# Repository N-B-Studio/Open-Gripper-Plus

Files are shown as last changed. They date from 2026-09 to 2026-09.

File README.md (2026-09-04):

# Open-Gripper-Plus

An open robotic gripper built around a cycloidal gear actuator, dual ODrive motor control, and an STM32H723 control board.

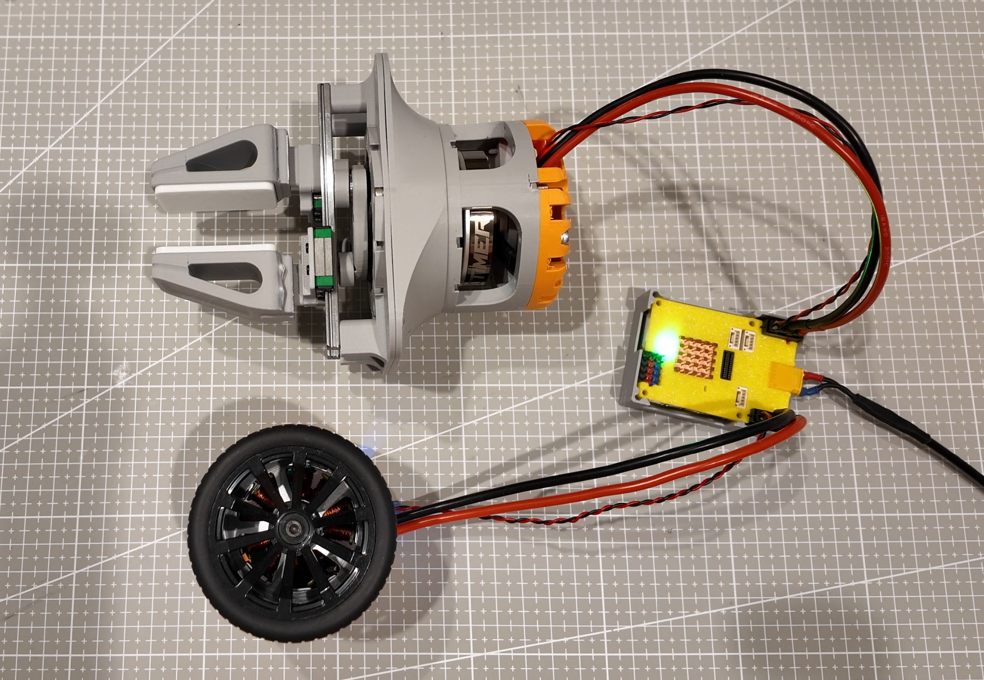
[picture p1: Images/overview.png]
Open-Gripper-Plus assembled prototype


## Overview

Open-Gripper-Plus combines a compact mechanical gripper with embedded control electronics for synchronized actuator operation. The repository includes the mechanical CAD files and the STM32 firmware project used to communicate with the motor controllers.

## Features

- Cycloidal gear actuator and custom gripper parts
- STM32H723VGT6 control board
- Dual FDCAN interfaces for ODrive communication
- BMI088 accelerometer and gyroscope support over SPI
- 1 kHz control loop with position synchronization and torque limits
- UART logging and WS2812 status LEDs

## Repository Layout

```text
3D Model/
	5010+Cycloidal+Gear+Actuator/  Reference actuator CAD
	modified part/                 Custom gripper and actuator parts
Images/                          Project images
STM32-H723/                      STM32CubeIDE firmware project
```

## Firmware

The firmware project is located in [`STM32-H723/`](STM32-H723/). The CubeMX configuration is [`vla-arm.ioc`](STM32-H723/vla-arm.ioc), and the application entry point is [`main.c`](STM32-H723/Core/Src/main.c).

The controller assigns two motor nodes to the leader and follower axes and exchanges motor state over FDCAN. Control parameters such as spring gain, damping, follow ratio, deadband, and torque limits are defined near the top of `main.c`.

### Build

Open [`STM32-H723/vla-arm.ioc`](STM32-H723/vla-arm.ioc) or the project in STM32CubeIDE, select the `Debug` or `Release` configuration, and build for the STM32H723VGT6 target. The generated build output is placed in the corresponding `STM32-H723/Debug/` or `STM32-H723/Release/` directory.

Before powering the actuator, verify the motor node IDs, CAN wiring, motor enable wiring, torque limits, and mechanical travel for your hardware.

## Mechanical Files

The `3D Model/modified part/` directory contains the custom STEP parts:

- `motor-base.step`
- `part-1.step` through `part-6.step`

The `3D Model/5010+Cycloidal+Gear+Actuator/` directory contains the reference actuator model.

## License

This project is released under the [MIT License](LICENSE).

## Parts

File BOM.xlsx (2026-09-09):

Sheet: gribber
Name | Quantitiy | Spec | Taobao
BLDC Motor | 2 | 5010 260kv
M3 bolt | few | 8mm 10mm 12mm 14mm
Bearings | 4
Steel rods | 4 | m3*10 | https://item.taobao.com/item.htm?id=959105247455
Linear rails | 2 | MGN7 100mm | https://item.taobao.com/item.htm?id=762564601721
Linear rail blocks / carriages | 2 | MGN7C | https://item.taobao.com/item.htm?id=762564601721
Bearings | 4 | 3*10*4 | https://detail.tmall.com/item.htm?id=704126548333
Optional components:
Wheels / tyres | 1 | 601-6085 | https://item.taobao.com/item.htm?id=45362002229
Control board |  | DA-kit STM32-H723 | https://item.taobao.com/item.htm?id=775424549365
FOC motor drivers | 2 | MINI_Odrive foc Turing | https://item.taobao.com/item.htm?id=842070935339
Wires
M2 nylon screws | 4 | mount mini-odrive (m2*10) | https://detail.tmall.com/item.htm?id=601483585366
M2 heat-set threaded inserts | 4 | M2*3*3.5 | https://detail.tmall.com/item.htm?id=809364062256

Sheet: gearbox
Category | Item | Description | Quantity | Cost USD | Total Cost USD | US Link | Cost RMB | Total Cost RMB | China Link
 | Bearing | MR106-2RS | Bearing between input shaft and cycloidal disk, and between input shaft and output shaft | 13 | $0.87 | $11.31 | https://www.amazon.com/dp/B082PSCNKB?ref_=cm_sw_r_cp_ud_dp_XR6N8JQ34JH0ZSWHT5HK (https://www.amazon.com/dp/B082PSCNKB?skipTwisterOG=1&newOGT=1) | ¥0.90 | ¥11.70 | https://detail.tmall.com/item.htm?abbucket=9&id=728753970557&skuId=5050168324949
 |  | 6701-2RS | Bearing between cycloidal disk and output shaft | 2 | $0.94 | $1.88 | https://www.amazon.com/gp/product/B082PQ8DC2 | ¥2.30 | ¥4.60 | https://detail.tmall.com/item.htm?abbucket=9&id=672836796497&skuId=5017505094887
 |  | 6809ZZ | Bearing between output shaft and housing | 2 | $2.26 | $4.52 | https://www.amazon.com/gp/product/B082PQQP7W | ¥3.89 | ¥7.78 | https://detail.tmall.com/item.htm?abbucket=8&id=695287603935&ns=1&skuId=5102438922481
 | Fastener | M3 x 55 mm | Mounting housing | 4 | $0.26 | $1.04 | https://www.amazon.com/gp/product/B01N68JLPE/ | ¥0.35 | ¥1.40 | https://detail.tmall.com/item.htm?abbucket=8&id=654819932601&skuId=5014407101270
 |  | M3 x 25 mm | Mounting output shaft | 6 | $0.19 | $1.14 | https://www.amazon.com/gp/product/B0967ZWJMM | ¥0.07 | ¥0.42 | https://detail.tmall.com/item.htm?abbucket=8&id=654819932601&skuId=5014407101291
 |  | M2 x 3 x 3.5 mm | M2 threaded insert for mounting encoder | 4 | $0.07 | $0.28 | https://www.amazon.com/dp/B0B8GN63S2 | ¥0.08 | ¥0.32 | https://detail.tmall.com/item.htm?abbucket=15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
 |  | M3 x 4 x 5 mm insert | M3 threaded insert | 24 | $0.08 | $1.92 | https://www.amazon.com/gp/product/B0BTYF2MMD | ¥0.13 | ¥3.12 | https://item.taobao.com/item.htm?id=593581996419&skuId=4189077672129
 |  | M4 x 12 mm hex stand | input shaft stiffener | 1 | $0.40 | $0.40 | https://www.amazon.com/uxcell-Female-Threaded-Standoff-Pillar/dp/B018RSONJK?s=industrial | ¥0.26 | ¥0.26 | https://detail.tmall.com/item.htm?abbucket=8&id=645528391157
 | Motor | MAD Components 5010 110KV |  | 1 | $84.00 | $84.00 | https://www.amazon.com/gp/product/B082W5B5LZ | ¥448.00 | ¥448.00 | https://item.taobao.com/item.htm?abbucket=8&id=534590842464
 | Structural | PLA | 3D print filament, in kg | 0.1 | $25.99 | $2.60 | https://www.amazon.com/gp/product/B00J0GMMP6 | ¥79.00 | ¥7.90 | https://detail.tmall.com/item.htm?abbucket=8&id=693972799714
 | Electrical | B-G431B-ESC1 | Motor controller | 1 | $18.97 | $18.97 | https://www.digikey.com/en/products/detail/stmicroelectronics/B-G431B-ESC1/10321670 | ¥165.00 | ¥165.00 | https://item.taobao.com/item.htm?abbucket=8&id=656153143517
 |  | AS5600 | I2C position encoder | 1 | $3.30 | $3.30 | https://www.amazon.com/gp/product/B09LMB3PTZ | ¥5.40 | ¥5.40 | https://item.taobao.com/item.htm?abbucket=8&id=828546819482
 |  | Misc | Cables & connectors | 1 | $5.00 | $5.00 |  | ¥20.00 | ¥20.00
 | Total |  |  |  |  | $136.36 |  |  | ¥675.90
reference： | https://berkeley-humanoid-lite.gitbook.io/docs/getting-started-with-hardware/materials-and-parts-bom
print-file： | https://makerworld.com/en/models/1279205-5010-cycloidal-gear-actuator?from=search#profileId-1364911

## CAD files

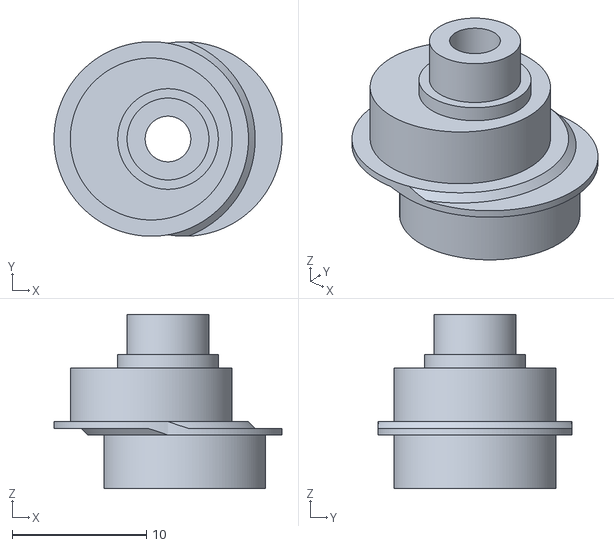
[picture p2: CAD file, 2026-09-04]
3D Model/5010+Cycloidal+Gear+Actuator/Input Shaft - Bambu - Input Shaft.stl
17.0 x 14.5 x 13.0

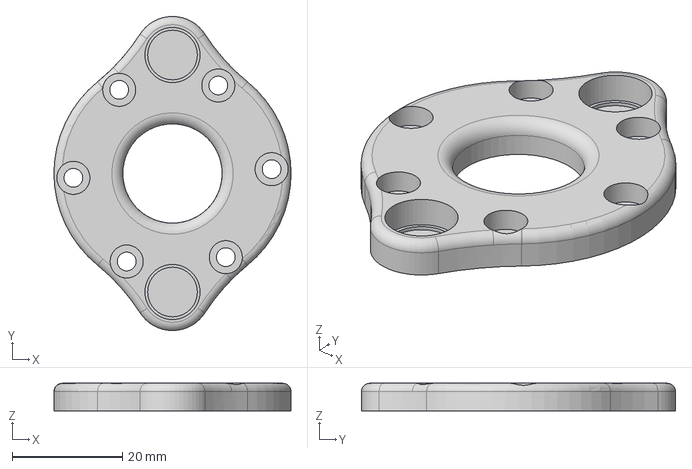
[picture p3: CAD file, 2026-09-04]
3D Model/modified part/part-4.step
43.0 x 57.0 x 5.00 mm

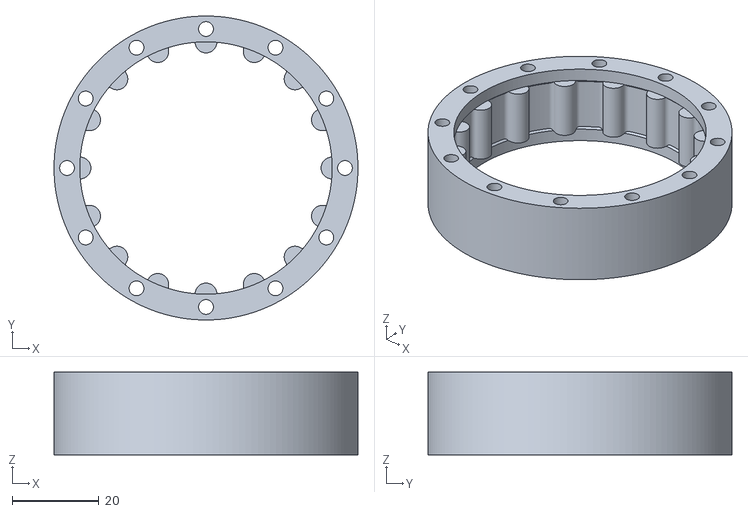
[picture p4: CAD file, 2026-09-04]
3D Model/5010+Cycloidal+Gear+Actuator/Housing - Bambu - Housing Middle.stl
70.0 x 70.0 x 19.0

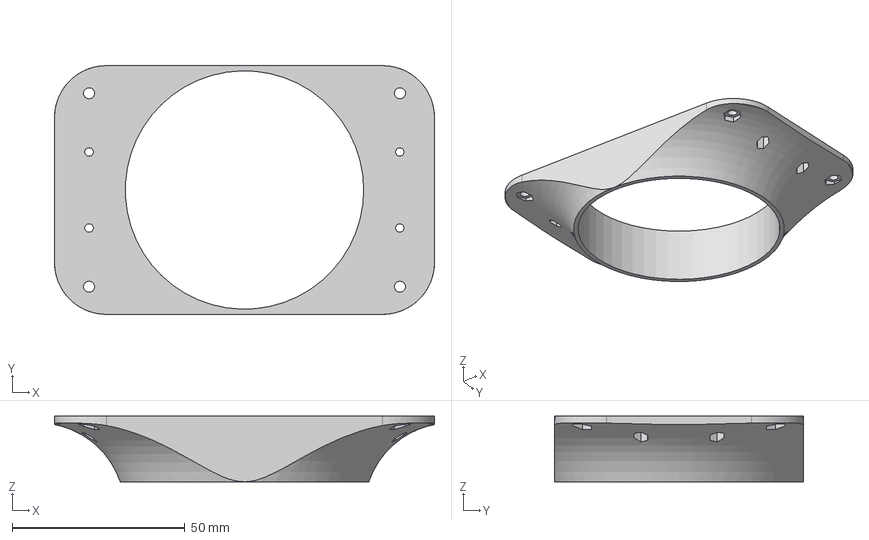
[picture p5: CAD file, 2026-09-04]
3D Model/modified part/part-2.step
110.0 x 72.0 x 19.0 mm

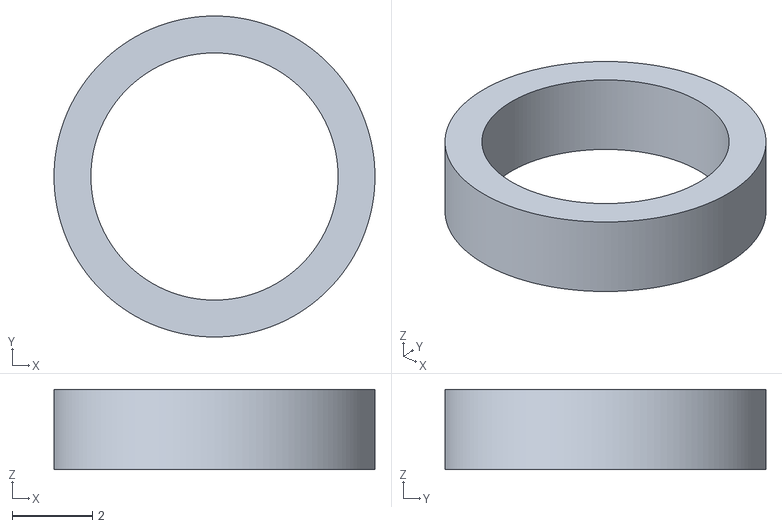
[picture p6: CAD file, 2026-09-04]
3D Model/5010+Cycloidal+Gear+Actuator/Output - Bambu - Output Shaft Spacer.stl
8.00 x 8.00 x 2.00

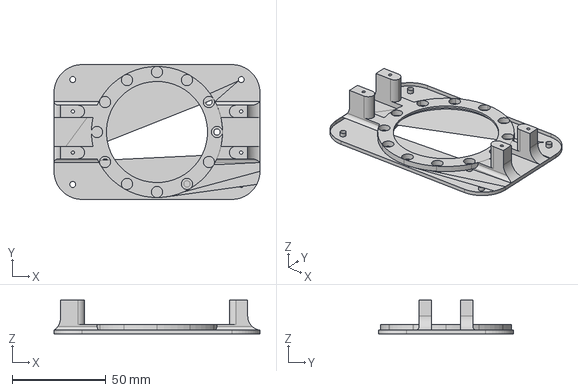
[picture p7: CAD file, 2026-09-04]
3D Model/modified part/part-3.step
110.0 x 72.0 x 18.0 mm

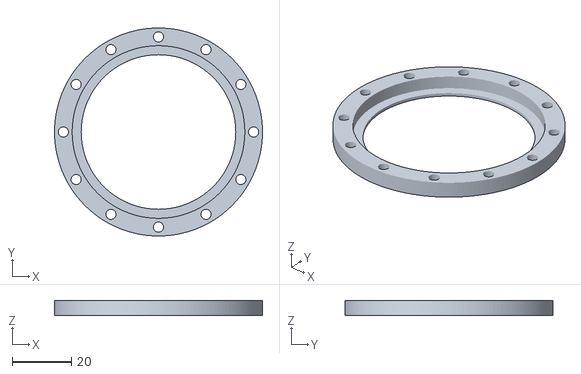
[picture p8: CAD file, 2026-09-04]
3D Model/5010+Cycloidal+Gear+Actuator/Housing - Bambu - Housing Rear.stl
70.0 x 70.0 x 5.00

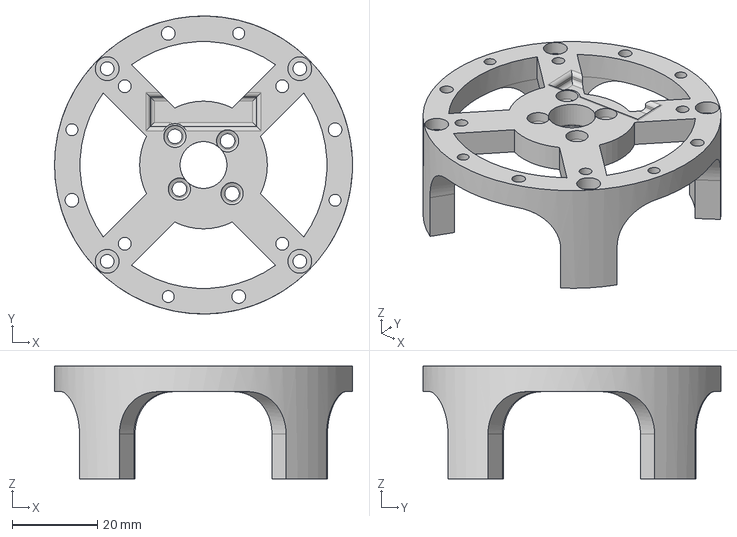
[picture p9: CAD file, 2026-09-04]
3D Model/modified part/motor-base.step
70.0 x 70.0 x 26.5 mm

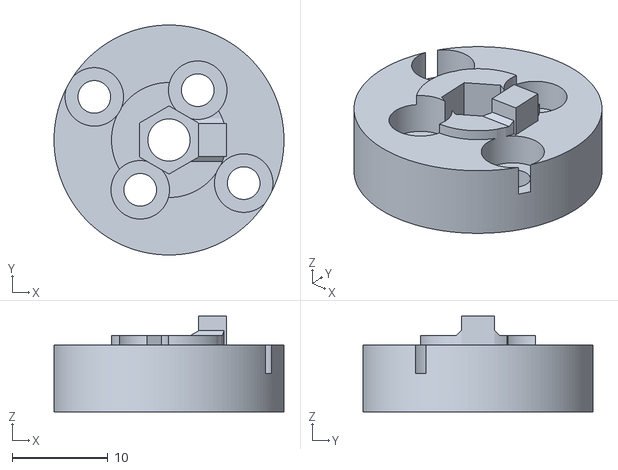
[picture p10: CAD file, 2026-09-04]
3D Model/5010+Cycloidal+Gear+Actuator/Motor Shaft - Bambu - Motor Shaft.stl
24.0 x 24.0 x 10.0

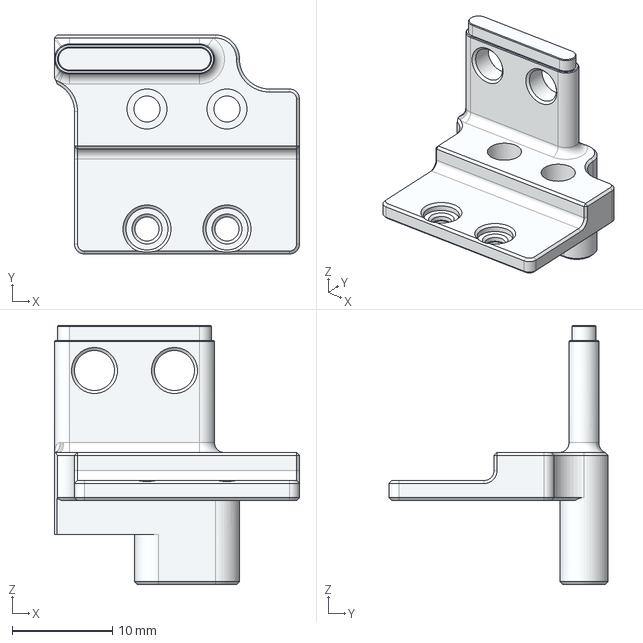
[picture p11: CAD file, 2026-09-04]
3D Model/modified part/part-6.step
24.5 x 21.9 x 25.9 mm

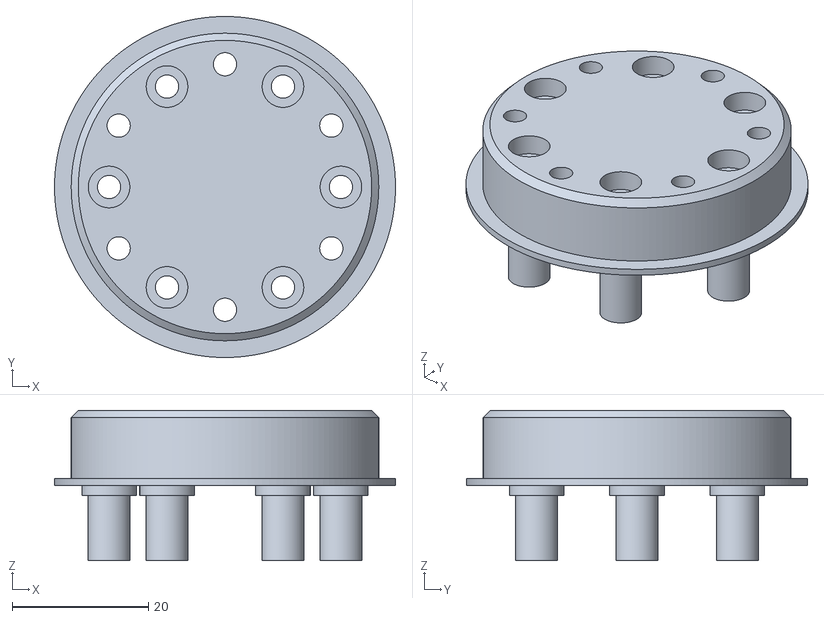
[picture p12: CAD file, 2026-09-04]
3D Model/5010+Cycloidal+Gear+Actuator/Output - Bambu - Output Shaft Front.stl
50.0 x 50.0 x 22.0

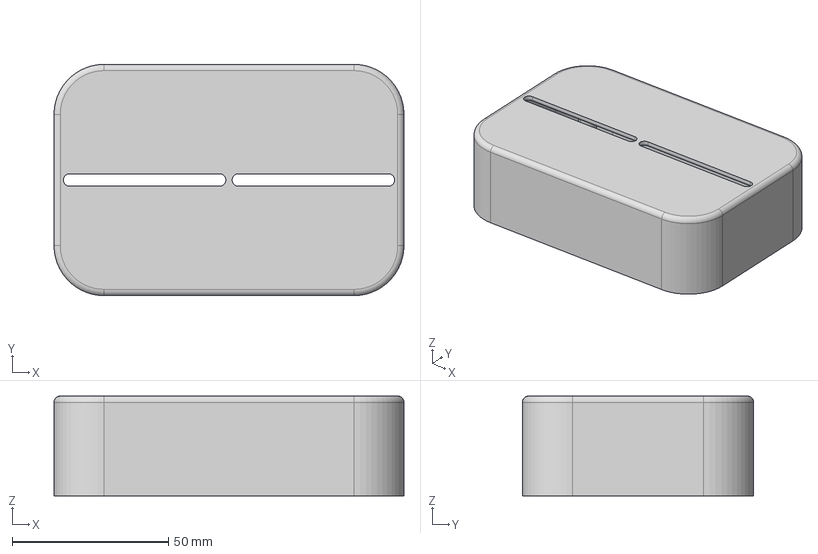
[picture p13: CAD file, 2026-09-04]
3D Model/modified part/part-5.step
112.0 x 74.0 x 32.0 mm

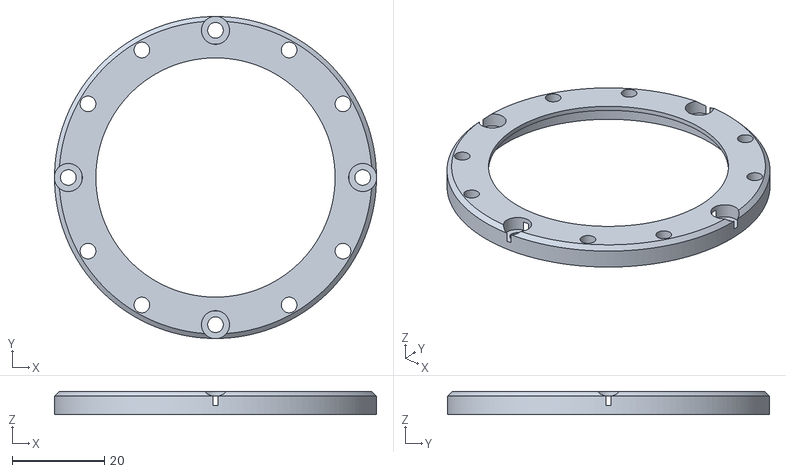
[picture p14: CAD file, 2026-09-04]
3D Model/5010+Cycloidal+Gear+Actuator/Housing - Bambu - Housing Front.stl
70.0 x 70.0 x 5.00

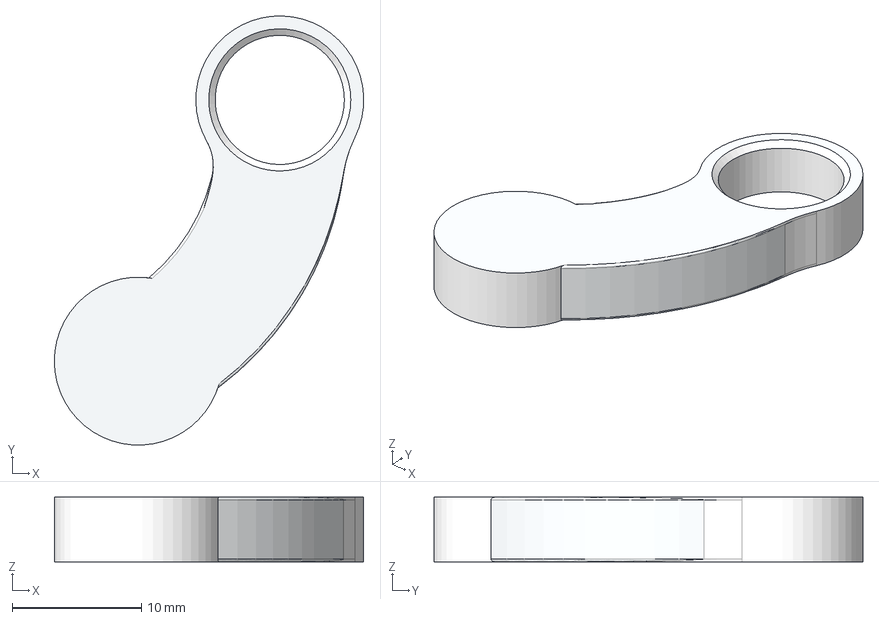
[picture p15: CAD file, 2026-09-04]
3D Model/modified part/part-1.step
23.9 x 33.2 x 5.00 mm

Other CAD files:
3D Model/5010+Cycloidal+Gear+Actuator/Output - Bambu - Output Shaft Rear.stl
3D Model/5010+Cycloidal+Gear+Actuator/Cycloidal Disk - Bambu - Cycloidal Disk.stl
3D Model/5010+Cycloidal+Gear+Actuator/Motor Shell - Motor Shell.stl

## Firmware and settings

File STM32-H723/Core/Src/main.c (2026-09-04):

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
/* Includes ------------------------------------------------------------------*/
#include "main.h"
#include "dma.h"
#include "fdcan.h"
#include "spi.h"
#include "tim.h"
#include "usart.h"
#include "gpio.h"

/* USER CODE BEGIN PD */
#include "ws2812.h"
#include "bsp_fdcan.h"
#include <stdio.h>
#include <string.h>
#include <stdarg.h>
#include <math.h>
/* USER CODE END PD */

/* USER CODE BEGIN PM */
typedef struct {
    uint8_t node_id;
    float pos_turns;
    float vel_turns_s;
    float torque_target_nm;
    float torque_estimate_nm;
    uint32_t axis_error;
    uint8_t axis_state;
    uint32_t hb_count;
    uint32_t enc_count;
    uint32_t tq_count;
    uint32_t last_rx_ms;
} ODriveState;

#define NODE_LEADER    1   // motor on CAN1
#define NODE_FOLLOWER  2   // motor on CAN2

static ODriveState leader   = {NODE_LEADER,   0};
static ODriveState follower = {NODE_FOLLOWER, 0};

extern volatile uint32_t can1_raw_rx_count;
extern volatile uint32_t can2_raw_rx_count;

extern volatile uint16_t can1_last_rx_id;
extern volatile uint16_t can2_last_rx_id;
/* USER CODE END PM */


/* USER CODE BEGIN PV */
volatile uint8_t loop_1khz_flag = 0;
static uint32_t loop_count = 0;
static uint32_t can_tx_drop = 0;
static uint32_t can_rx_other = 0;

#define CTRL_DIV 1   // 1=1kHz, 2=500Hz, 4=250Hz, 10=100Hz

/* Bidirectional virtual spring parameters */
static float K_SPRING = 0.02f;

/* Absolute velocity damping for leader/follower */
static float D_ABS_L = 0.005f;
static float D_ABS_F = 0.0002f;

/* Keep 1:1 initially. After stability confirmed, can change to 7.0f */
static float FOLLOW_RATIO = 15.0f;

/* Velocity low-pass filter coefficient */
static float VEL_LPF_ALPHA = 0.15f;

/* Continuous position deadband, about 0.2 degrees */
static float ERR_DEADBAND_RAD = 0.0035f;

/* Maximum sync error to prevent torque saturation during fast motion */
static float ERR_MAX_RAD = 1.20f;

/* Maximum torque for each side */
static float TAU_MAX_L = 0.80f;
static float TAU_MAX_F = 0.60f;


/* USER CODE END PV */

void SystemClock_Config(void);
/* USER CODE BEGIN 0 */
static inline void led_yellow(void){ WS2812_Ctrl(60, 60, 0); }
static inline void led_red(void)   { WS2812_Ctrl(80, 0, 0);  }
static inline void led_green(void) { WS2812_Ctrl(0, 80, 0);  }

static char logbuf[224];

static void log_uart1(const char *s)
{
    HAL_UART_Transmit(&huart1, (uint8_t*)s, (uint16_t)strlen(s), 100);
}

static void logf_uart1(const char *fmt, ...)
{
    va_list ap;
    va_start(ap, fmt);
    int n = vsnprintf(logbuf, sizeof(logbuf), fmt, ap);
    va_end(ap);
    if (n < 0) return;
    size_t len = strnlen(logbuf, sizeof(logbuf));
    HAL_UART_Transmit(&huart1, (uint8_t*)logbuf, (uint16_t)len, 100);
}

#define MOTOR_EN_PORT GPIOC
#define MOTOR_EN_PIN_1  GPIO_PIN_14
#define MOTOR_EN_PIN_2  GPIO_PIN_13

static inline void arm_enable(uint8_t en)
{
    HAL_GPIO_WritePin(MOTOR_EN_PORT, MOTOR_EN_PIN_1, en ? GPIO_PIN_SET : GPIO_PIN_RESET);
    HAL_GPIO_WritePin(MOTOR_EN_PORT, MOTOR_EN_PIN_2, en ? GPIO_PIN_SET : GPIO_PIN_RESET);
}

static uint32_t le_u32(const uint8_t *d)
{
    return ((uint32_t)d[0]) | ((uint32_t)d[1] << 8) | ((uint32_t)d[2] << 16) | ((uint32_t)d[3] << 24);
}

static float le_float(const uint8_t *d)
{
    float f;
    uint32_t u = le_u32(d);
    memcpy(&f, &u, sizeof(float));
    return f;
}

static void put_u32_le(uint8_t *d, uint32_t v)
{
    d[0] = (uint8_t)(v & 0xFF);
    d[1] = (uint8_t)((v >> 8) & 0xFF);
    d[2] = (uint8_t)((v >> 16) & 0xFF);
    d[3] = (uint8_t)((v >> 24) & 0xFF);
}

static inline uint16_t odrive_id(uint8_t node_id, uint8_t cmd_id)
{
    return (uint16_t)((node_id << 5) | (cmd_id & 0x1F));
}

static int odrive_send(FDCAN_HandleTypeDef *hcan, uint8_t node_id, uint8_t cmd_id, const uint8_t *data, uint32_t len)
{
    uint8_t payload[8] = {0};
    if (data && len > 0) {
        if (len > 8) len = 8;
        memcpy(payload, data, len);
    }
    int r = fdcanx_send_data(hcan, odrive_id(node_id, cmd_id), payload, len);
    if (r != 0) can_tx_drop++;
    return r;
}

static int odrive_clear_errors(FDCAN_HandleTypeDef *hcan, uint8_t node_id)
{
    return odrive_send(hcan, node_id, 0x18, NULL, 0);
}

static int odrive_set_axis_state(FDCAN_HandleTypeDef *hcan, uint8_t node_id, uint32_t state)
{
    uint8_t d[4];
    put_u32_le(d, state);
    return odrive_send(hcan, node_id, 0x07, d, 4);
}

static int odrive_set_controller_mode(FDCAN_HandleTypeDef *hcan, uint8_t node_id, uint32_t control_mode, uint32_t input_mode)
{
    uint8_t d[8];
    put_u32_le(&d[0], control_mode);
    put_u32_le(&d[4], input_mode);
    return odrive_send(hcan, node_id, 0x0B, d, 8);
}

void can_parse_feedback(uint16_t rx_id, uint8_t *d, uint8_t len)  // called from bsp_fdcan.c
{
    if (len < 1) return;

    uint8_t node = (uint8_t)(rx_id >> 5);
    uint8_t cmd  = (uint8_t)(rx_id & 0x1F);

    ODriveState *m = NULL;
    if (node == NODE_LEADER) {
        m = &leader;
    } else if (node == NODE_FOLLOWER) {
        m = &follower;
    } else {
        can_rx_other++;
        return;
    }

    switch (cmd) {
        case 0x01: // Heartbeat: Axis_Error uint32, Axis_State uint8 at byte 4
            if (len >= 8) {
                m->axis_error = le_u32(&d[0]);
                m->axis_state = d[4];
                m->hb_count++;
                m->last_rx_ms = HAL_GetTick();
            }
            break;

        case 0x09: // Get_Encoder_Estimates: pos turns, vel turns/s
            if (len >= 8) {
                m->pos_turns = le_float(&d[0]);
                m->vel_turns_s = le_float(&d[4]);
                m->enc_count++;
                m->last_rx_ms = HAL_GetTick();
            }
            break;

        case 0x1C: // Get_Torques: target Nm, estimate Nm. Only if enabled/requested.
            if (len >= 8) {
                m->torque_target_nm = le_float(&d[0]);
                m->torque_estimate_nm = le_float(&d[4]);
                m->tq_count++;
                m->last_rx_ms = HAL_GetTick();
            }
            break;

        default:
            break;
    }
}

static void fatal(const char *msg)
{
    led_red();
    logf_uart1("[FATAL] %s\r\n", msg);
    arm_enable(0);
    __disable_irq();
    while (1) { HAL_Delay(1000); }
}

static inline float clampf(float x, float lo, float hi)
{
    if (x > hi) return hi;
    if (x < lo) return lo;
    return x;
}

static void put_float_le(uint8_t *d, float f)
{
    uint32_t u;
    memcpy(&u, &f, sizeof(float));
    put_u32_le(d, u);
}

static int odrive_set_input_torque(FDCAN_HandleTypeDef *hcan,
                                   uint8_t node_id,
                                   float torque_nm)
{
    uint8_t d[4];
    put_float_le(d, torque_nm);

    return odrive_send(hcan, node_id, 0x0E, d, 4);
}
   /* 
static int odrive_set_input_pos(FDCAN_HandleTypeDef *hcan, uint8_t node_id, float pos_turns)
{
    uint8_t d[8] = {0};
    put_float_le(&d[0], pos_turns);   // input_pos, turns
    return odrive_send(hcan, node_id, 0x0C, d, 8);
}
*/
/* USER CODE END 0 */

/**
  * @brief  The application entry point.
  * @retval int
  */
int main(void)
{
  HAL_Init();
  SystemClock_Config();

  MX_GPIO_Init();
  MX_DMA_Init();
  MX_SPI2_Init();
  MX_USART1_UART_Init();
  MX_TIM2_Init();
  MX_FDCAN1_Init();
  MX_FDCAN2_Init();
  MX_USART10_UART_Init();
  MX_SPI6_Init();

  /* USER CODE BEGIN 2 */
  led_yellow();
  log_uart1("\r\n[BOOT] ODrive barebone CAN closed-loop demo\r\n");

  arm_enable(0);
  HAL_Delay(50);

  log_uart1("[INIT] CAN...\r\n");
  bsp_can_init();
  HAL_Delay(50);

  HAL_FDCAN_ActivateNotification(&hfdcan1, FDCAN_IT_RX_FIFO0_NEW_MESSAGE, 0);
  HAL_Delay(50);
  HAL_FDCAN_ActivateNotification(&hfdcan2, FDCAN_IT_RX_FIFO0_NEW_MESSAGE, 0);

  HAL_TIM_Base_Start_IT(&htim2);

  log_uart1("[INIT] motor power enable\r\n");
  arm_enable(1);
  HAL_Delay(500);

  log_uart1("[INIT] clear errors\r\n");
  odrive_clear_errors(&hfdcan1, NODE_LEADER);
  HAL_Delay(50);
  odrive_clear_errors(&hfdcan2, NODE_FOLLOWER);
  HAL_Delay(100);
  log_uart1("[INIT] torque control + passthrough\r\n");

	// control_mode = 1  torque control ； input_mode   = 1  passthrough
	if (odrive_set_controller_mode(&hfdcan1, NODE_LEADER, 1, 1) != 0)
	{
		fatal("mode leader");
	}

	HAL_Delay(50);

	if (odrive_set_controller_mode(&hfdcan2, NODE_FOLLOWER, 1, 1) != 0)
	{
		fatal("mode follower");
	}

	HAL_Delay(50);

	odrive_set_input_torque(&hfdcan1, NODE_LEADER, 0.0f);
	odrive_set_input_torque(&hfdcan2, NODE_FOLLOWER, 0.0f);
	HAL_Delay(20);

  log_uart1("[INIT] closed loop\r\n");
  if (odrive_set_axis_state(&hfdcan1, NODE_LEADER, 8) != 0) fatal("closed leader");
  HAL_Delay(100);
  if (odrive_set_axis_state(&hfdcan2, NODE_FOLLOWER, 8) != 0) fatal("closed follower");
  HAL_Delay(100);

  led_green();
  logf_uart1("[OK] running. leader=%d follower=%d\r\n", NODE_LEADER, NODE_FOLLOWER);
  /* USER CODE END 2 */

  /* USER CODE BEGIN WHILE */

  while (1)
  {
    if (!loop_1khz_flag) continue;
    loop_1khz_flag = 0;
    loop_count++;
    if ((loop_count % CTRL_DIV) != 0) continue;

    // ================ Main control loop start =================

    static uint8_t zero_initialized = 0;

    static float zero_L_turns = 0.0f;
    static float zero_F_turns = 0.0f;

    static float tauL_prev = 0.0f;
    static float tauF_prev = 0.0f;

    static float wL_filt = 0.0f;
    static float wF_filt = 0.0f;
    static uint8_t vel_filter_initialized = 0;

    uint32_t now_ms = HAL_GetTick();

    uint8_t can_ok =
        (leader.axis_state == 8) &&
        (follower.axis_state == 8) &&
        (leader.enc_count > 0) &&
        (follower.enc_count > 0) &&
        (leader.tq_count > 0) &&
        (follower.tq_count > 0) &&
        ((now_ms - leader.last_rx_ms) < 20) &&
        ((now_ms - follower.last_rx_ms) < 20);

    float err_rad = 0.0f;
    float rel_vel_rad_s = 0.0f;

    float tau_couple = 0.0f;

    float tauL_cmd = 0.0f;
    float tauF_cmd = 0.0f;

    int r1 = 0;
    int r2 = 0;

    if (!zero_initialized && can_ok)
    {
        zero_L_turns = leader.pos_turns;
        zero_F_turns = follower.pos_turns;

        zero_initialized = 1;

        logf_uart1(
            "[ZERO] L %.4f turns F %.4f turns\r\n",
            zero_L_turns,
            zero_F_turns
        );
    }

    if (zero_initialized && can_ok)
    {
        float qL_rad =
            (leader.pos_turns - zero_L_turns) * 6.28318530718f;

        float qF_rad =
            (follower.pos_turns - zero_F_turns) * 6.28318530718f;

        float wL_raw =
            leader.vel_turns_s * 6.28318530718f;

        float wF_raw =
            follower.vel_turns_s * 6.28318530718f;

        /* Initialize velocity filter to avoid slow ramp-up from zero at startup */
        if (!vel_filter_initialized)
        {
            wL_filt = wL_raw;
            wF_filt = wF_raw;
            vel_filter_initialized = 1;
        }
        else
        {
            wL_filt +=
                VEL_LPF_ALPHA *
                (wL_raw - wL_filt);

            wF_filt +=
                VEL_LPF_ALPHA *
                (wF_raw - wF_filt);
        }

        float wL_rad_s = wL_filt;
        float wF_rad_s = wF_filt;

        /*
        * Proportional sync error:
        * equilibrium when qF = FOLLOW_RATIO * qL
        */
        err_rad =
            FOLLOW_RATIO * qL_rad
            - qF_rad;

        /*
        * When the leader spins quickly, the follower may temporarily lag.
        * Limit the controller error to prevent the spring term from saturating for too long.
        */
        err_rad = clampf(
            err_rad,
            -ERR_MAX_RAD,
            ERR_MAX_RAD
        );

        /*
         * For logging only. Control damping uses each side's own velocity,
         * not the more delay-sensitive relative velocity damping.
         */
        rel_vel_rad_s =
            FOLLOW_RATIO * wL_rad_s
            - wF_rad_s;

        /*
         * Continuous position deadband to avoid abrupt spring torque switching near standstill.
         */
        float spring_err_rad;

        if (err_rad > ERR_DEADBAND_RAD)
        {
            spring_err_rad = err_rad - ERR_DEADBAND_RAD;
        }
        else if (err_rad < -ERR_DEADBAND_RAD)
        {
            spring_err_rad = err_rad + ERR_DEADBAND_RAD;
        }
        else
        {
            spring_err_rad = 0.0f;
        }
        /*
         * Standard bidirectional virtual spring.
         * The same spring torque acts on both motors in opposite directions.
         */
        tau_couple =
            K_SPRING * spring_err_rad;

        /* Leader feels the reaction torque from the follower */
        tauL_cmd =
            -tau_couple
            - D_ABS_L * wL_rad_s;

        /* Follower follows leader */
        tauF_cmd =
             tau_couple
            - D_ABS_F * wF_rad_s;

        tauL_cmd = clampf(
            tauL_cmd,
            -TAU_MAX_L,
            TAU_MAX_L
        );

        tauF_cmd = clampf(
            tauF_cmd,
            -TAU_MAX_F,
            TAU_MAX_F
        );

        /*
        * Torque rate limit.
        * Prevent telemetry spikes from causing sudden torque command changes.
        */
        /* Disable slew limiter during diagnostics */
        tauL_prev = tauL_cmd;
        tauF_prev = tauF_cmd;

        r1 = odrive_set_input_torque(
            &hfdcan1,
            NODE_LEADER,
            tauL_cmd
        );

        r2 = odrive_set_input_torque(
            &hfdcan2,
            NODE_FOLLOWER,
            tauF_cmd
        );
    }
    else
    {
        tauL_prev = 0.0f;
        tauF_prev = 0.0f;

        r1 = odrive_set_input_torque(
            &hfdcan1,
            NODE_LEADER,
            0.0f
        );

        r2 = odrive_set_input_torque(
            &hfdcan2,
            NODE_FOLLOWER,
            0.0f
        );
    }

    // ================ Main control loop end ===================

    static uint32_t last_log_ms = 0;

    uint32_t now = HAL_GetTick();

    if ((now - last_log_ms) >= 50)
    {
        last_log_ms = now;

        logf_uart1(
            "e %.2fdeg dv %.3f | "
            "cmdL %.4f cmdF %.4f spring %.4f | "
            "L q %.2f v %.3f tqE %.4f st %u age %lu | "
            "F q %.2f v %.3f tqE %.4f st %u age %lu | "
            "enc %lu/%lu tq %lu/%lu r %d/%d drop %lu\r\n",

            err_rad * 57.2957795f,
            rel_vel_rad_s,

            tauL_cmd,
            tauF_cmd,
            tau_couple,

            (leader.pos_turns - zero_L_turns) * 360.0f,
            leader.vel_turns_s,
            leader.torque_estimate_nm,
            leader.axis_state,
            (unsigned long)(now - leader.last_rx_ms),

            (follower.pos_turns - zero_F_turns) * 360.0f,
            follower.vel_turns_s,
            follower.torque_estimate_nm,
            follower.axis_state,
            (unsigned long)(now - follower.last_rx_ms),

            (unsigned long)leader.enc_count,
            (unsigned long)follower.enc_count,
            (unsigned long)leader.tq_count,
            (unsigned long)follower.tq_count,

            r1,
            r2,
            (unsigned long)can_tx_drop
        );
    }
  }
  /* USER CODE END WHILE */
}

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
/* USER CODE BEGIN 4 */
void HAL_TIM_PeriodElapsedCallback(TIM_HandleTypeDef *htim)
{
    if (htim->Instance == TIM2)
    {
        loop_1khz_flag = 1;
    }
}

/* USER CODE END 4 */
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
